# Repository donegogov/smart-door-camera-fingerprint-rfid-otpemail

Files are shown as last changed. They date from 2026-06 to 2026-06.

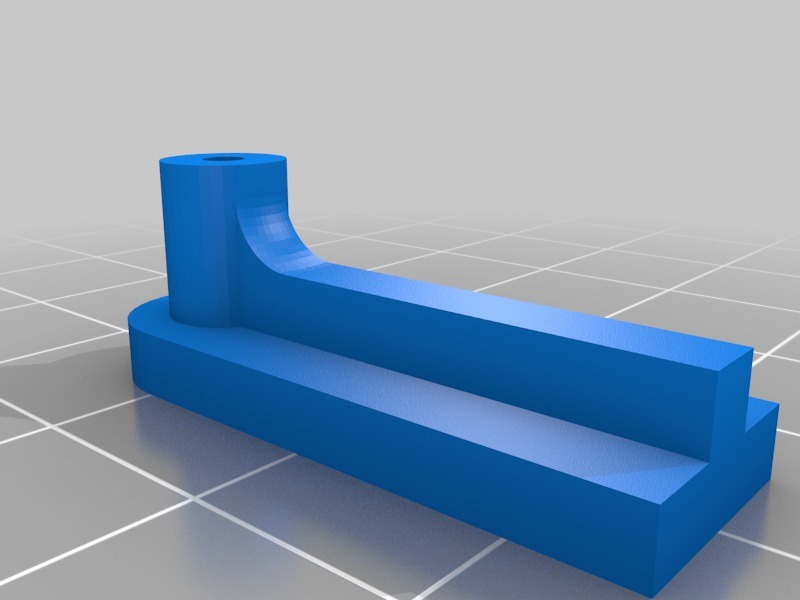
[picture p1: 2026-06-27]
stl for smart door/Super Compact Pan Tilt Camera Mount - 107957/images/bracket.jpg

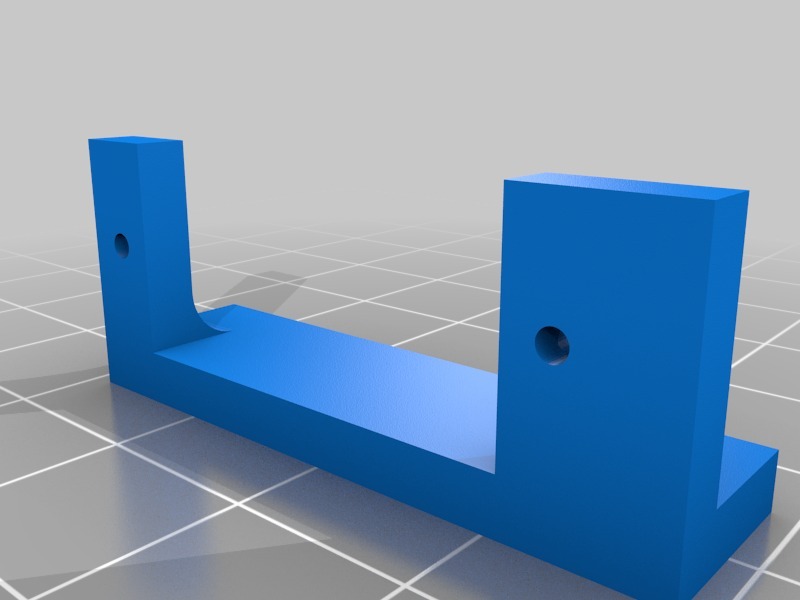
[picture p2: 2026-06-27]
stl for smart door/Super Compact Pan Tilt Camera Mount - 107957/images/vertMount.jpg

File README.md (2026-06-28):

if you like my work donate some crypto

Bitcoin: bc1p0pmdvk0g86z0apl4l9f0rgymtfvcjtlekkm47hyptl5zf8ask6hqpf82un

Ethereum: 0x4F641266B906AcEA1Ed106FDD50978EE5337e3e7

Solana: 4UCTxasy88uFfBvxVqoLxvh8sPomCSJ1Ljoxbf5Xc1ef

# 🔒 Pametna Vrata — Multi-Layer Smart Door Security System

Sistem za pametno zakluchuvanje so **5 sloevi na zashtita**, izgraden na
Raspberry Pi. Raboti kako **dopolnitelen sloj** nad obichnata brava so kluc.

> **Vazhno:** Ova e DIY/hobi proekt i DOPOLNITELEN sloj na zashtita. Obichnata
> brava so kluc OSTANUVA glavnata zashtita. Ne se potпiraj samo na ova za
> vistinska bezbednost na dom.

---

## 📋 Sodrzhina
1. Shto pravi sistemot
2. Arhitektura (zoshto DVA uredi)
3. Shto ti treba (hardver)
4. Povrzuvanje (pinout)
5. Instalacija od NULA
6. Mrezha (Ethernet megju dvata Pi)
7. TLS sertifikati
8. Enroll (lica, otpechatoci, kartichki)
9. Pushtanje
10. Shtelovanje i problemi
11. Bezbednost — kako raboti

---

## 1. Shto pravi sistemot

Koga nekoj ke se priblizhi do vratata:

1. 📷 **Kamera na pan/tilt** detektira dvizhenje i SLEDI go liceto (mazno)
2. 🧠 **Face recognition** — proveruva dali e poznat chlen ili nepoznat
   - Nepoznat → praka ALERT email so slika do sopstvenikot
   - Poznat → prodolzhuva na sledniot sloj
3. 👆 **Otpechatok od prst**
4. 📧 **OTP kod** — ispraten na email, se vnesuva na tastatura
5. 💳 **RFID kartichka**

Ako SITE 5 proverki pominat → vratata se otkluchuva.
LCD ekran prikazhuva status na sekoj chekor.

---

## 2. Arhitektura — zoshto DVA uredi?

Sistemot koristi **dva Raspberry Pi** za maksimalna bezbednost:

```
   NADVOR (RPi4, na vratata)            VNATRE (RPi5, zad vratata)
   +----------------------+            +----------------------+
   | • Kamera + serva      |            | • Face recognition    |
   | • Otpechatok, RFID    |  Ethernet  | • Site proverki       |
   | • Tastatura, LCD      |<==(TLS)==> | • Bazi + tajni        |
   | • SLEDI lokalno       |            | • OTP (email)         |
   | x NEMA tajni          |            | • ODLUCHUVA           |
   | x NEMA bazi           |            | • Komanduva BRAVA     |
   | x NE odluchuva        |            | 🔒 BRAVA (vnatre)     |
   +----------------------+            +----------------------+
```

**Zoshto vaka?** Nadvoreshniot Pi e fizichki dostapen (napagjach moze da go
dofati). Zatoa toj NEMA nishto vredno — bez tajni, bez bazi, bez moc da
otkluchи. Samo CHITA senzori i PRAKA surovi podatoci vnatre. Mozokot
(odluka + brava) e VNATRE, nedostapen.

Duri i da nekoj go ukrade ili hakira nadvoreshniot Pi → dobiva bezvreden
"preprakjach". Ne moze da otkluchi bez da pomine SITE proverki vnatre.

---

## 3. Shto ti treba (hardver)

| Komponenta | Uloga | Kade |
|---|---|---|
| Raspberry Pi 4 (4-8GB) | sledi + senzori | NADVOR |
| Raspberry Pi 5 | mozok + odluka | VNATRE |
| Pi Camera v3 (NoIR za nok) | lice | NADVOR |
| SunFounder Fusion HAT+ | serva + napojuvanje | NADVOR |
| 2x servo (pan/tilt) | dvizhenje na kamera | NADVOR |
| Fingerprint senzor (UART) | otpechatok | NADVOR |
| RC522 RFID chitac | kartichki | NADVOR |
| 4x4 tastatura | OTP vnes | NADVOR |
| 16x2 LCD (I2C) | status | NADVOR |
| Rele + brava (FAIL-SECURE) | zakluchuvanje | VNATRE |
| Ethernet kabel + armored door loop | vrska | megju dvata |

**Napojuvanje:** NADVOR preku Fusion HAT+ (eden 5V/3A USB-C za Pi+serva).
VNATRE obichen RPi5 napojuvac (5V/5A).

> **NoIR kamera** = gleda vo temnina so IR svetlo. Dobro za vrata. Preku den
> boite izgledaat malku rozevo.

---

## 4. Povrzuvanje (pinout)

Site pinovi se **BCM** broevi.

### NADVOR (RPi4)
| Komponenta | Povrzuvanje |
|---|---|
| **Serva pan/tilt** | Fusion HAT kanali **P0** (pan), **P1** (tilt) |
| **Fingerprint** UART | TX→GPIO15, RX→GPIO14, 3.3V, GND (`/dev/serial0`) |
| **RC522** SPI | SDA→GPIO8, SCK→GPIO11, MOSI→GPIO10, MISO→GPIO9, RST→GPIO25, **3.3V**, GND |
| **Tastatura 4x4** | redovi 19,13,6,5 / koloni 21,20,22,27 |
| **LCD I2C** | SDA→GPIO2, SCL→GPIO3 (**hardverska i2c-1**), 5V, GND |
| **Vrska kon VNATRE** | Ethernet (eth0) |

> ⚠️ RC522 SAMO na **3.3V** (na 5V gori!). Fingerprint TX↔RX se VKRSTENI.

### VNATRE (RPi5)
| Komponenta | Pin |
|---|---|
| Rele za brava | GPIO17 (FAIL-SECURE: bez struja = zakluceno) |
| Ethernet | eth0 → kon NADVOR |
| Monitor | HDMI |

---

## 5. Instalacija od NULA

### 5.1 — Snimi OS na dvete SD kartichki
Koristi **Raspberry Pi Imager**. Za OBATA:
- OS: **Raspberry Pi OS (64-bit) — Bookworm**
- Vo postavki (⚙️): vkluchi SSH, postavi korisnik/lozinka, WiFi

### 5.2 — Prv boot i azhuriranje (OBATA)
```bash
sudo apt update && sudo apt full-upgrade -y
```

### 5.3 — Svali go proektot
Stavi ja `nadvor/` papka na RPi4, `vnatre/` papka na RPi5.

### 5.4 — Pushti install skripta

**NADVOR (RPi4):**
```bash
cd nadvor
chmod +x install_nadvor.sh
./install_nadvor.sh
sudo reboot
```
**VNATRE (RPi5):**
```bash
cd vnatre
chmod +x install_vnatre.sh
./install_vnatre.sh
sudo reboot
```

> ⏳ Na VNATRE, dlib KOMPAJLIRA 10-30 min. Normalno. NADVOR e pobrz (nema dlib).

### 5.5 — Sekogash aktiviraj venv pred rabota
```bash
cd nadvor   # ili vnatre
source venv/bin/activate
```

---

## 6. Mrezha — Ethernet megju dvata Pi

Preporachano: **direkten kabel Pi-na-Pi** so staticki IP.

> Bookworm koristi **NetworkManager** (ne dhcpcd!). Koristi `nmcli`.

Najdi go imeto na ethernet vrskata:
```bash
nmcli con show          # baraj "ethernet" tip (npr "eth0" ili "Wired connection 1")
```

**VNATRE (RPi5)** — IP 10.0.0.1:
```bash
sudo nmcli con mod "<ime>" ipv4.method manual ipv4.addresses 10.0.0.1/24
sudo nmcli con mod "<ime>" ipv4.never-default yes
sudo nmcli con up "<ime>"
```
**NADVOR (RPi4)** — IP 10.0.0.2:
```bash
sudo nmcli con mod "<ime>" ipv4.method manual ipv4.addresses 10.0.0.2/24
sudo nmcli con mod "<ime>" ipv4.never-default yes
sudo nmcli con up "<ime>"
```

Povrzhi go kabelot (obata Pi vkluceni!), pa testiraj od NADVOR:
```bash
ping 10.0.0.1     # treba da odgovara
```
Vo `nadvor/config_vrska.py` proveri: `VNATRE_IP = "10.0.0.1"`

> Ethernet kabelot pominuva niz **armored door cable** (povrshinski, bez dupcenje dzid).

---

## 7. TLS sertifikati (sifrirana vrska)

Pushti **EDNASH**:
```bash
chmod +x generiraj_sertifikati.sh
./generiraj_sertifikati.sh
```
Kopiraj:
- **VNATRE** (vnatre/): `ca.crt`, `vnatre.crt`, `vnatre.key`
- **NADVOR** (nadvor/): `ca.crt`, `nadvor.crt`, `nadvor.key`

> 🔑 `ca.key` chuvaj go OFFLINE. Privatnite `.key` NIKOGASH ne gi sodeluvaj.

---

## 8. Enroll — lica, otpechatoci, kartichki

Senzorite se NADVOR, bazите VNATRE → dva chekori.

### 8.1 LICA
NADVOR:
```bash
cd nadvor && source venv/bin/activate
python3 headshots.py        # ime, SPACE=slikaj, Q=kraj (10-15 sliki/chlen)
```
Kopiraj `dataset/` na VNATRE, pa:
```bash
cd vnatre && source venv/bin/activate
python3 train_model.py      # pravi encodings.pickle
```

### 8.2 OTPECHATOCI
NADVOR:
```bash
python3 enroll_otpechatok.py    # registriraj prst, zapamti finger_id
```
VNATRE — vo `otpechatoci.json`:
```json
{"1": "Done", "2": "Valentina", "3": "Vasil"}
```

### 8.3 RFID KARTICHKI
NADVOR:
```bash
python3 rfid_zapis.py       # zapisuva token, ti dava UID + Token
```
VNATRE:
```bash
python3 rfid_dodaj.py       # vnesi UID+Token, presmetuva hash, zachuvuva
```

### 8.4 Email (Mailgun) — na VNATRE
Vo `vnatre/.env` popolni `MAILGUN_API_KEY`, `MAILGUN_DOMAIN`, `ADMIN_EMAIL`.
Vo `vnatre/config_vnatre.py` smeni `EMAILS` so iminjata na familijata.

---

## 9. Pushtanje

**Prvo VNATRE (RPi5):**
```bash
cd vnatre && source venv/bin/activate && python3 server.py
```
**Potoa NADVOR (RPi4):**
```bash
cd nadvor && source venv/bin/activate && python3 main_nadvor.py
```

### Avtomatski na boot (systemd) — primer za VNATRE
```bash
sudo nano /etc/systemd/system/vrata.service
```
```ini
[Unit]
Description=Pametna Vrata
After=network.target

[Service]
User=donatello
WorkingDirectory=/home/donatello/vnatre
ExecStart=/home/donatello/vnatre/venv/bin/python /home/donatello/vnatre/server.py
Restart=on-failure

[Install]
WantedBy=multi-user.target
```
```bash
sudo systemctl enable vrata.service && sudo systemctl start vrata.service
```

---

## 10. Shtelovanje i chesti problemi

### Serva
| Problem | Reshenie |
|---|---|
| servo odi naopaku | `PAN_DIR`/`TILT_DIR` = -1 vo config.py |
| servo ne mrda | proveri kanal (P0/P1), kabli, Fusion HAT napojuvanje |

### Sledenje
| Problem | Reshenie |
|---|---|
| haoticno dvizhenje | namali `SCAN_STEP`, zgolemi `SCAN_DELAY` |
| ne gleda dvizhenje | namali `MIN_AREA` |
| premnogu osetlivo | zgolemi `MIN_AREA` i `THRESHOLD_SENSITIVITY` |

### Kamera
| Problem | Reshenie |
|---|---|
| ne bootira so HAT | proveri kabel na kamera (chest problem!) |
| mnogu zoom | `kamera.py` koristi ScalerCrop na cel senzor (full FoV) |
| lista prazna | kabel labav ili lош |

### Mrezha
| Problem | Reshenie |
|---|---|
| ping ne pominuva | proveri kabel, obata Pi vkluceni, IP adresi |
| `nmcli con up` greshka | kabelot mora da e povrzan PRVO |
| TLS greshka | sertifikatите kopirani vo dvete papki? |

### Fingerprint
| Problem | Reshenie |
|---|---|
| UART Input/output error | serial konzola iskluchena? TX↔RX vkrsteni? |

---

## 11. Bezbednost — kako raboti

| Sloj | Zashtita |
|---|---|
| **Mozok vnatre** | NADVOR nema tajni/bazi/odluka → ukraden = bezvreden |
| **TLS sifriranje** | nikoj na mrezhata ne moze da slusha/imitira |
| **OTP** | razlichen sekoj pat, na email → anti-replay |
| **RFID hash** | samo SHA-256 hash vnatre, salt ne patuva, kartichka bez lichni podatoci |
| **SSH kluc-samo** | bez lozinka, samo so privaten kluc |
| **FAIL-SECURE brava** | bez struja = zakluceno |
| **Obichen kluc** | GLAVNA zashtita — ova e DOPOLNITELEN sloj |

### SSH hardening
```bash
ssh-keygen -t ed25519              # na tvojot kompjuter
ssh-copy-id korisnik@<ip-na-Pi>
# vo /etc/ssh/sshd_config: PasswordAuthentication no
sudo systemctl restart ssh
```

---

## 📁 Struktura na fajlovi

### nadvor/ (RPi4)
```
main_nadvor.py       glavna (sledi + vodi niz faktori)
config.py            postavki (pinovi, kamera, serva)
config_vrska.py      IP na VNATRESHNIOT Pi
kamera.py            video stream
sledenje.py          Fusion HAT serva + motion
tastatura.py         4x4 tastatura
otpechatok.py        fingerprint
rfid_chitac.py       RFID (samo chita)
lcd.py               LCD status
vrska.py             TLS komunikacija
headshots.py         ALATKA: slikanje lica
enroll_otpechatok.py ALATKA: otpechatoci
rfid_zapis.py        ALATKA: RFID token
install_nadvor.sh    instalacija
generiraj_sertifikati.sh  TLS
```

### vnatre/ (RPi5)
```
server.py            glavna (TCP server + odluka + brava)
config_vnatre.py     postavki
prepoznavanje.py     face recognition
proverki.py          proverki (+ tajni/bazi)
email_notifikacija.py  Mailgun
brava.py             rele
vrska.py             TLS komunikacija
train_model.py       ALATKA: encodings.pickle
rfid_dodaj.py        ALATKA: RFID hash vo baza
install_vnatre.sh    instalacija
generiraj_sertifikati.sh  TLS
.env                 TAJNI - NE se sodeluva!
```

### Fajlovi shto TI gi pravish (ne se vo repo)
```
vnatre/encodings.pickle    lica
vnatre/korisnici.json      RFID hashevi
vnatre/otpechatoci.json    finger_id → ime
vnatre/.env                tajni
ca.crt, *.crt, *.key       TLS sertifikati
```

---

## ⚖️ Odgovornost

Edukativen/hobi proekt. Avtorot ne e odgovoren za bezbednost na tvoj dom.
Sekogash chuvaj ja obichnata brava so kluc kako GLAVNA zashtita.

Pridonesi i podobruvanja se dobredojdeni! 🚀

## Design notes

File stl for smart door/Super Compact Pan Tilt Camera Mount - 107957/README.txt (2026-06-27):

Super Compact Pan Tilt Camera Mount by AtomKemp on Thingiverse: https://www.thingiverse.com/thing:107957

Summary:
This was intended for use on a quad-rotor project, although it can be mounted on really anything. I used two Hitec HS-55 sub-micro servos and it whips the camera around without any problem. Enjoy!If you like this project, or would like to know more about 3D printing, check out my new book "The Makerspace Workbench" from Maker Media!

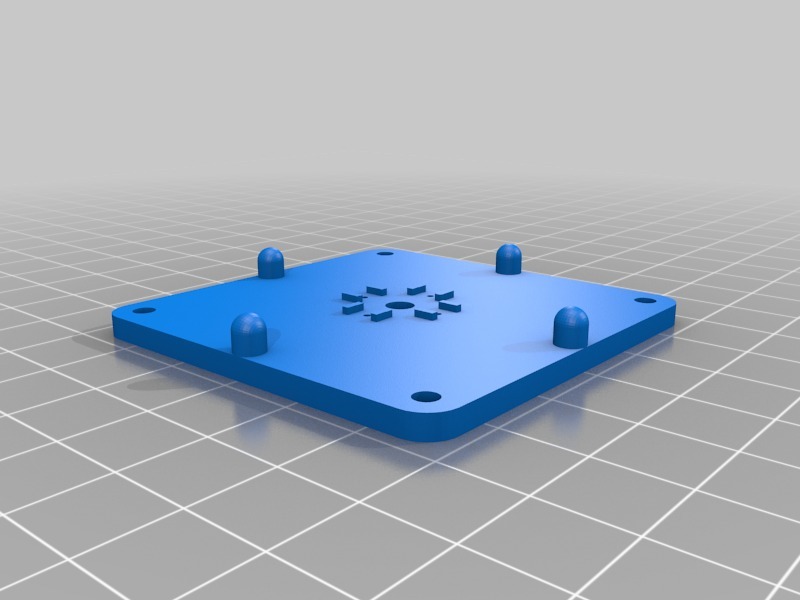
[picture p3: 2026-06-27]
stl for smart door/Super Compact Pan Tilt Camera Mount - 107957/images/panTiltBase.jpg

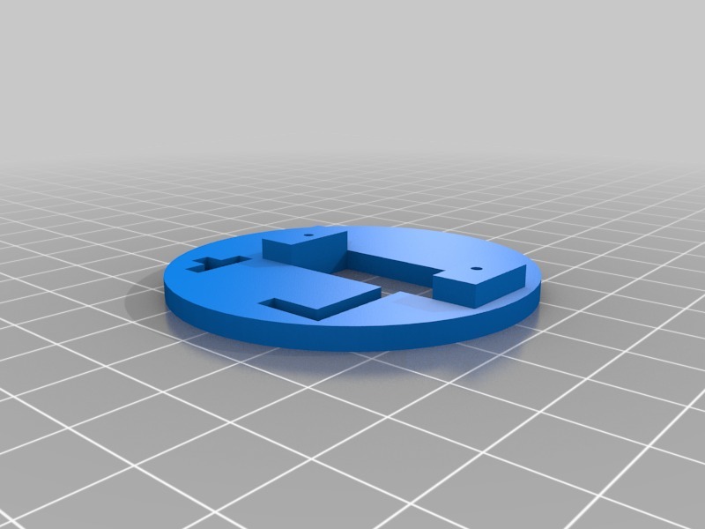
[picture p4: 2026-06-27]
stl for smart door/Super Compact Pan Tilt Camera Mount - 107957/images/panTilt.jpg

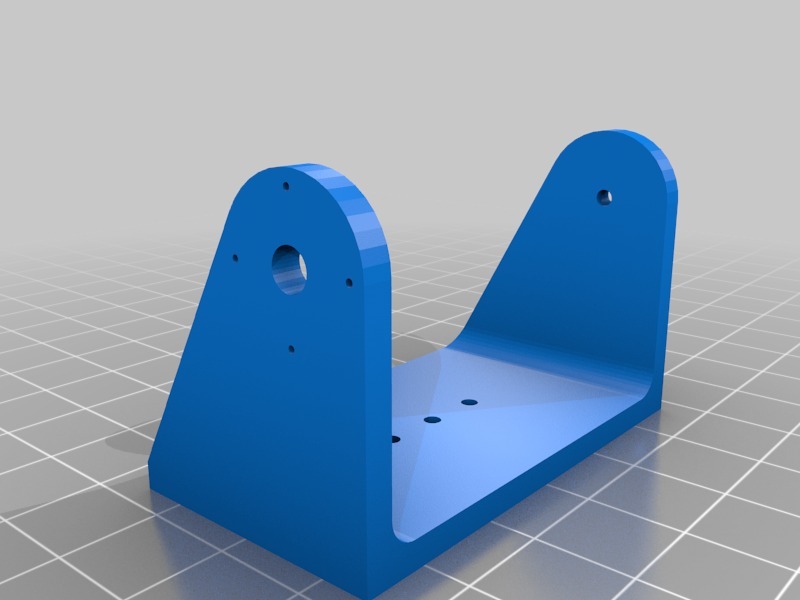
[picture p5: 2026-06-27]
stl for smart door/Super Compact Pan Tilt Camera Mount - 107957/images/cameraMount.jpg

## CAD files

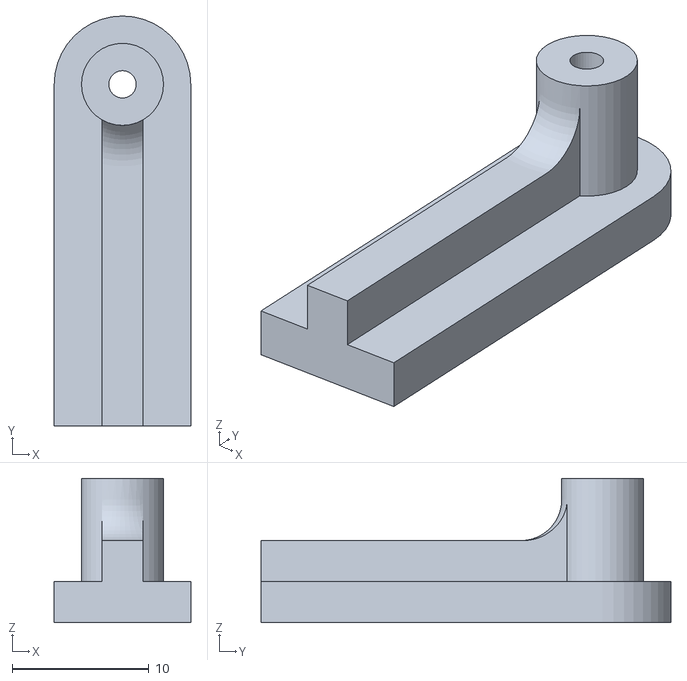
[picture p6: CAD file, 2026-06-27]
stl for smart door/Super Compact Pan Tilt Camera Mount - 107957/files/bracket.STL
10.0 x 30.0 x 10.6

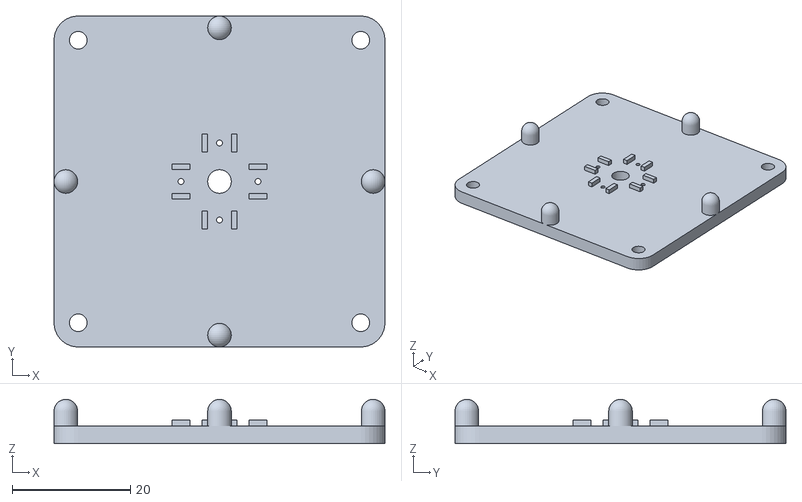
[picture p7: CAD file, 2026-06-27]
stl for smart door/Super Compact Pan Tilt Camera Mount - 107957/files/panTiltBase.STL
56.0 x 56.0 x 7.50

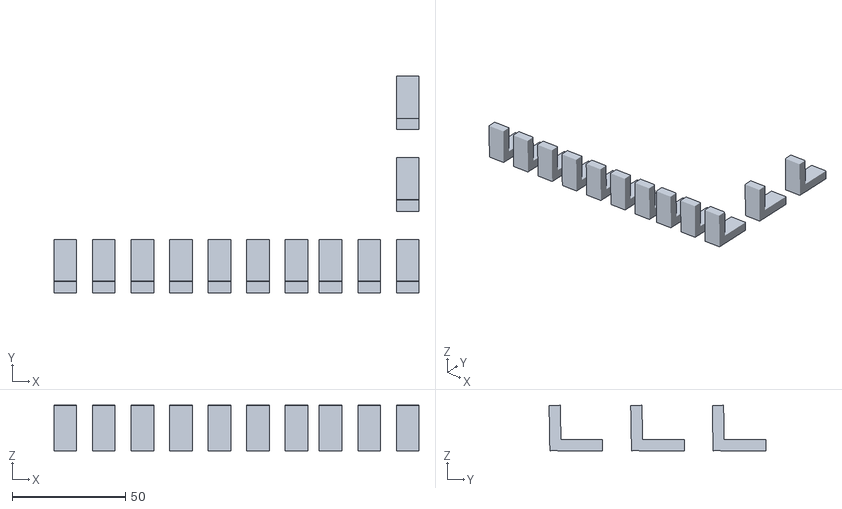
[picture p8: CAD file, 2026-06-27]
stl for smart door/drzaci.stl
161.0 x 95.7 x 20.1

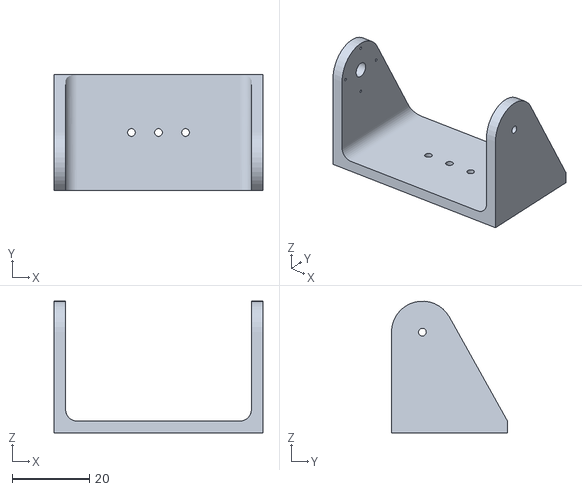
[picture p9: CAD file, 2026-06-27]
stl for smart door/Super Compact Pan Tilt Camera Mount - 107957/files/cameraMount.STL
54.0 x 30.0 x 34.0

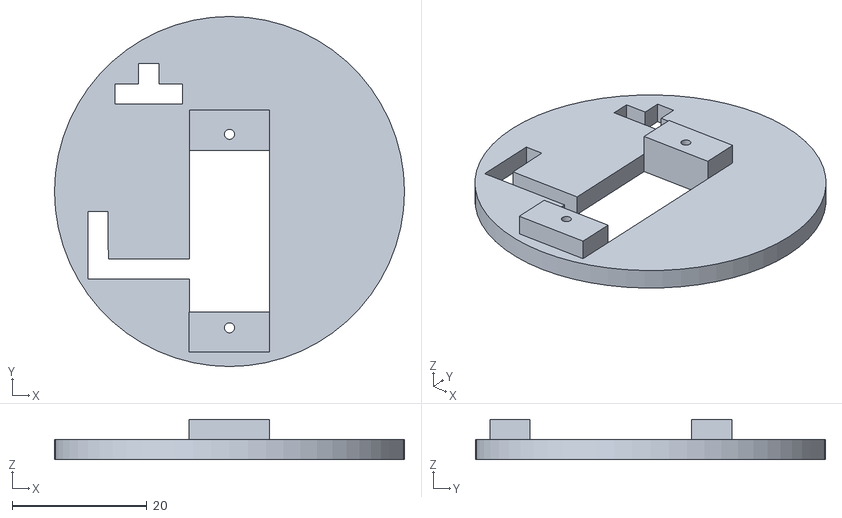
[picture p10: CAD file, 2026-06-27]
stl for smart door/Super Compact Pan Tilt Camera Mount - 107957/files/panTilt.STL
52.0 x 52.0 x 6.00

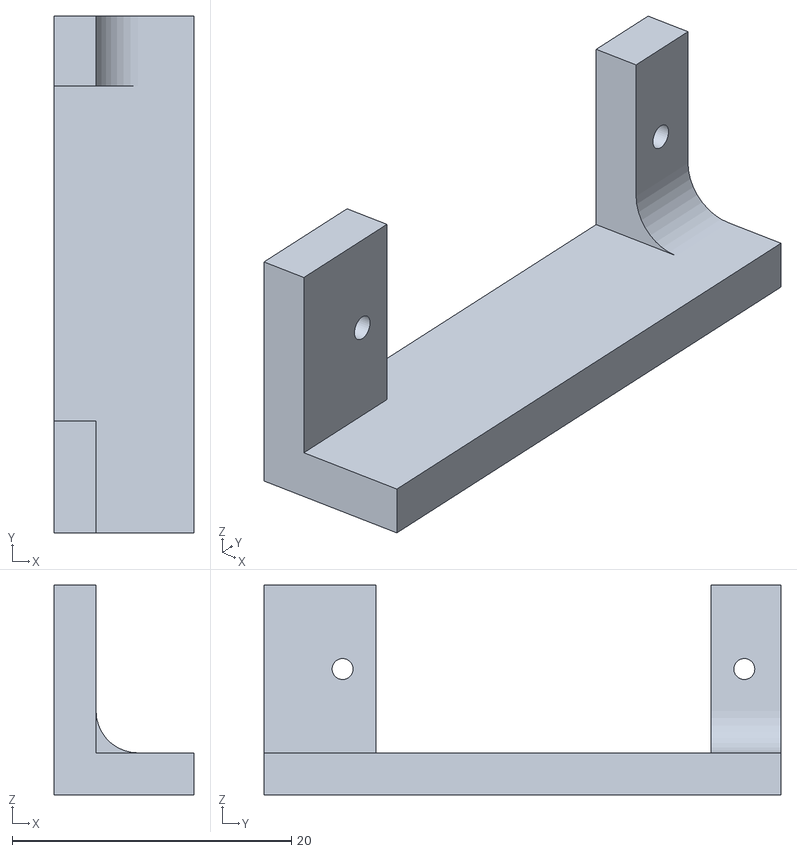
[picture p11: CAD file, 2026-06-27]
stl for smart door/Super Compact Pan Tilt Camera Mount - 107957/files/vertMount.STL
10.00 x 37.0 x 15.0

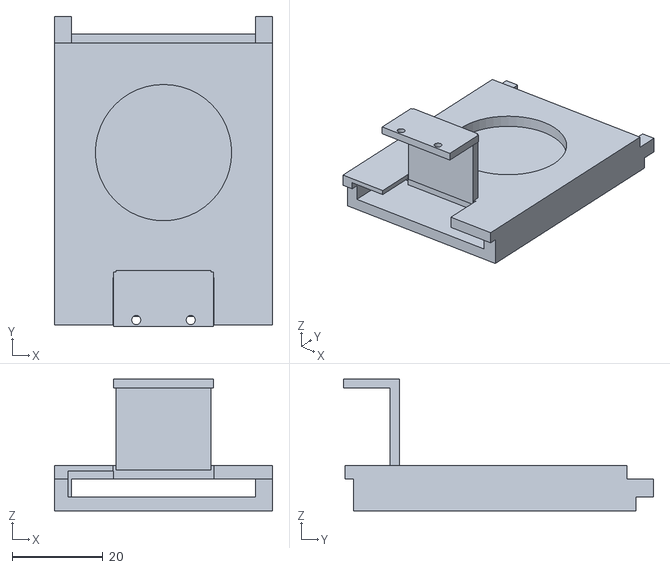
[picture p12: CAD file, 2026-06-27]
stl for smart door/rfid_housing_v1.3.stl
48.0 x 68.3 x 29.0

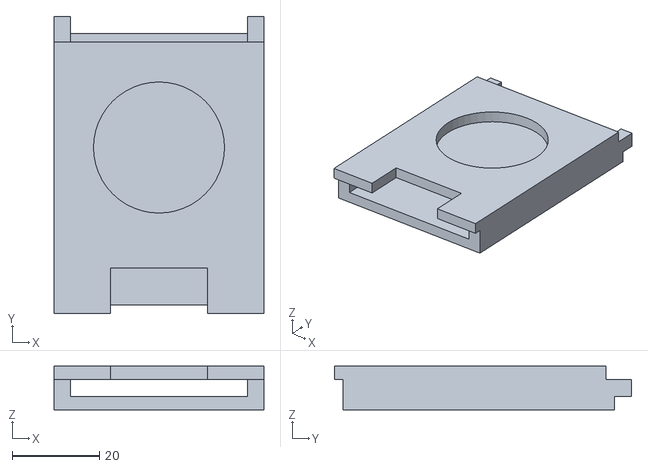
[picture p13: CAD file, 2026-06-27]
stl for smart door/rfid_housing.stl
48.0 x 68.0 x 10.0

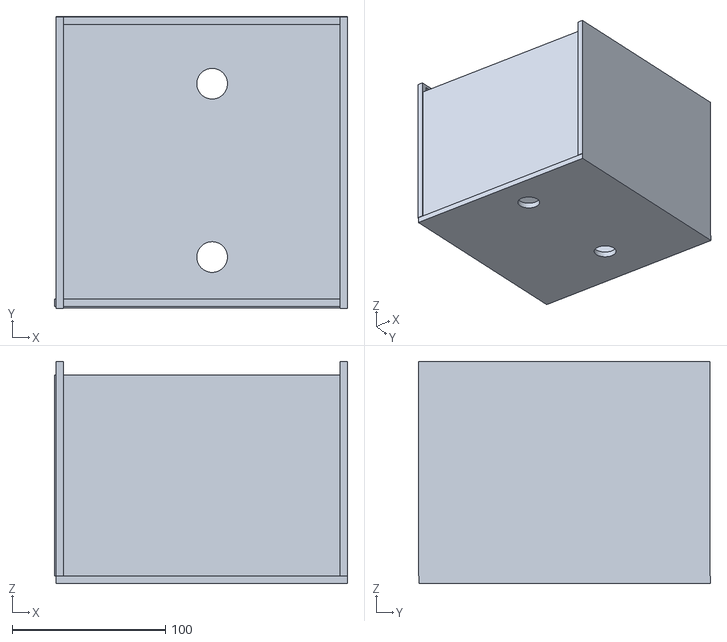
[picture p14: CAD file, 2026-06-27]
stl for smart door/razvodna_kutija_v2.0.stl
191.0 x 190.4 x 145.0

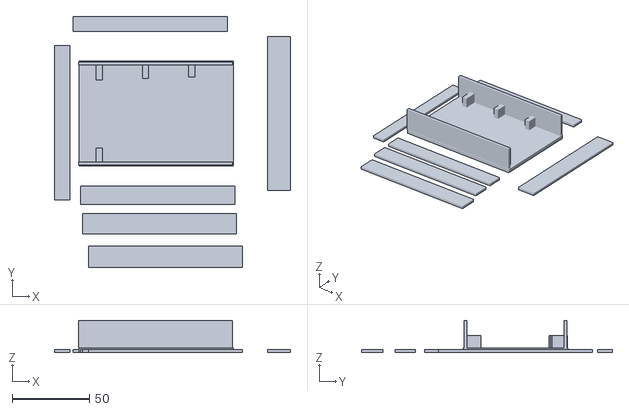
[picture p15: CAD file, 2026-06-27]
stl for smart door/lcd_housing_v2.stl
153.0 x 163.0 x 21.0

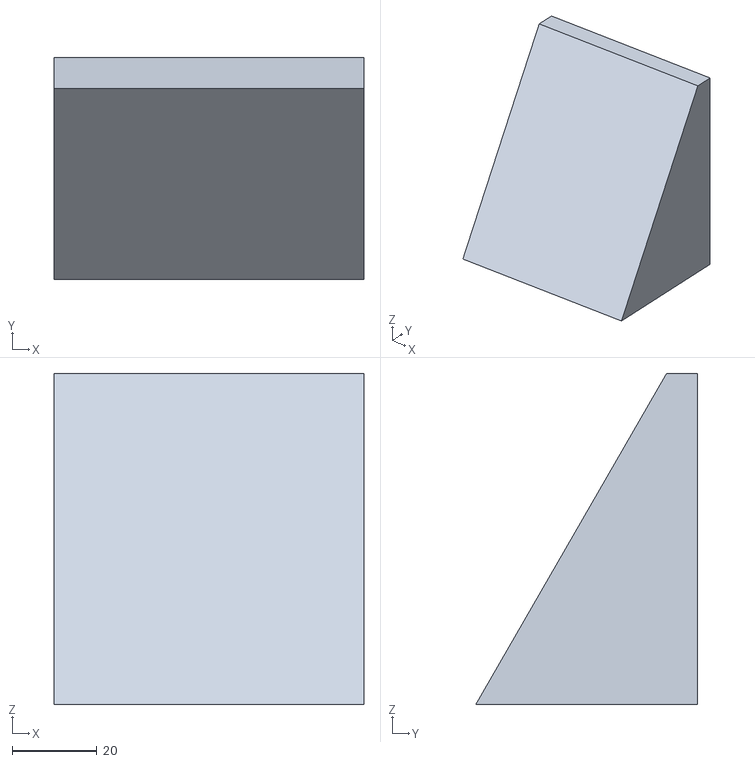
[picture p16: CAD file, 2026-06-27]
stl for smart door/tastatura_housing_v1.0.stl
73.0 x 52.2 x 78.0

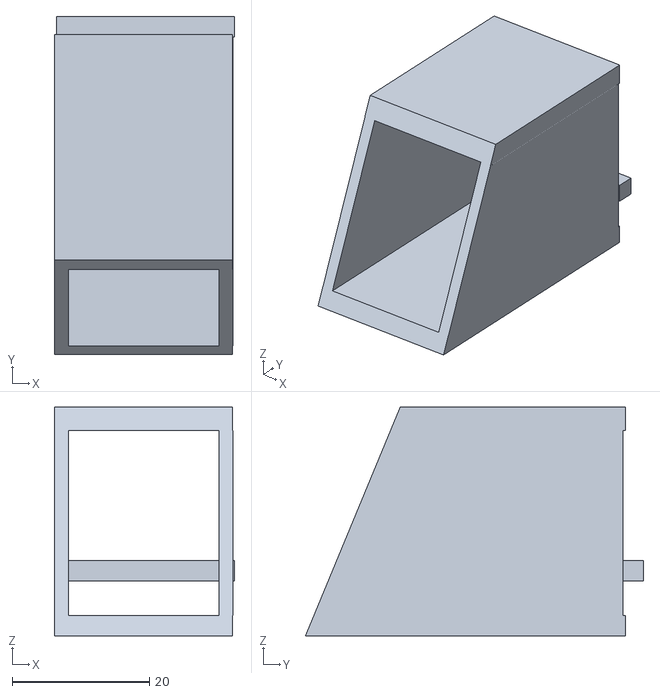
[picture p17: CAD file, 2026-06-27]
stl for smart door/fingerprint_housing_v2.0.stl
26.3 x 49.3 x 33.4

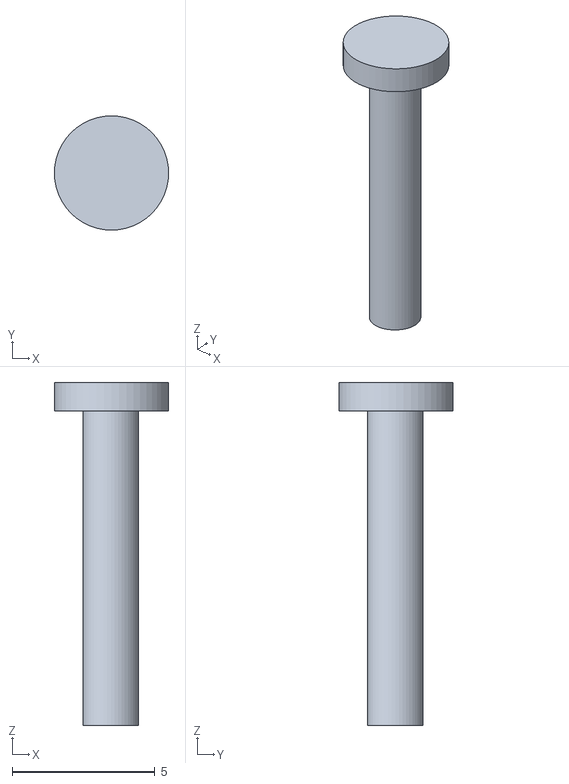
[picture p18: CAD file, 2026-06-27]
stl for smart door/rfid_screw.stl
4.00 x 4.00 x 12.0

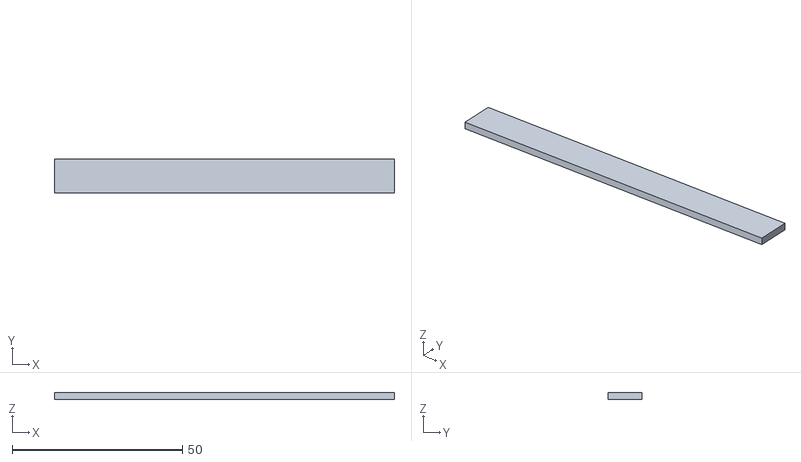
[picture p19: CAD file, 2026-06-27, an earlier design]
stl for smart door/lcd_housing_v1.1.stl
100.0 x 10.0 x 2.00

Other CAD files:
stl for smart door/fingerprint_housing_v1.1.stl
stl for smart door/fingerprint_housing_v1.0.stl
stl for smart door/lcd_housing_v1.2.stl
stl for smart door/razvodna_kutija_v1.0.stl
stl for smart door/lcd_housing_v1.0.stl
stl for smart door/lcd_housing_v1.3.stl
stl for smart door/rfid_housing_v1.1.stl
stl for smart door/rfid_housing_v1.2.stl

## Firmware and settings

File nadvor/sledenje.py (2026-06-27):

# -*- coding: utf-8 -*-
# sledenje.py
#
# SunFounder Fusion HAT:
#   PAN  = P0
#   TILT = P1
#
# Реални Fusion HAT агли:
#   PAN:  -30° до +30°
#   TILT: -90° горе до -60° долу
#
# Во функцијата postavi(x, y) продолжуваме да користиме логички 0-180:
#   PAN 60  -> Fusion -30°
#   PAN 90  -> Fusion   0°
#   PAN 120 -> Fusion +30°
#
#   TILT 0  -> Fusion -90° горе
#   TILT 15 -> Fusion -75° средина
#   TILT 30 -> Fusion -60° долу

import time
import math
from enum import Enum

import cv2
from fusion_hat.servo import Servo

import config as cfg

import numpy as np


# ============================================================
#                    ВИД НА ДВИЖЕЊЕ
# ============================================================

class MovementPattern(Enum):
    RECTANGLE = "rectangle"
    ELLIPSE = "ellipse"
    CIRCLE = "circle"
    INFINITY = "infinity"


# ОВДЕ ЈА ИЗБИРАШ ФОРМАТА:
MOVEMENT_PATTERN = MovementPattern.ELLIPSE

# Примери:
# MOVEMENT_PATTERN = MovementPattern.RECTANGLE
# MOVEMENT_PATTERN = MovementPattern.ELLIPSE
# MOVEMENT_PATTERN = MovementPattern.CIRCLE
# MOVEMENT_PATTERN = MovementPattern.INFINITY


# Колку секунди трае еден цел круг/елипса/осмица.
# Поголема вредност = побавно.
MOVEMENT_CYCLE_SECONDS = getattr(
    cfg,
    "MOVEMENT_CYCLE_SECONDS",
    10.0
)


# ============================================================
#                         CONFIG
# ============================================================
# Најмалку 5% од сликата мора да биде еден голем moving object.
MOTION_MIN_BLOB_RATIO = getattr(
    cfg,
    "MOTION_MIN_BLOB_RATIO",
    0.05
)

# Ако повеќе од 35% од целата слика се сменило,
# најверојатно се движела камерата.
MOTION_MAX_SCENE_CHANGE = getattr(
    cfg,
    "MOTION_MAX_SCENE_CHANGE",
    0.35
)

# Минимална ширина/висина на moving object.
MOTION_MIN_WIDTH_RATIO = getattr(
    cfg,
    "MOTION_MIN_WIDTH_RATIO",
    0.10
)

MOTION_MIN_HEIGHT_RATIO = getattr(
    cfg,
    "MOTION_MIN_HEIGHT_RATIO",
    0.20
)

# Колку последователни frames мора да има големо движење.
MOTION_CONFIRM_FRAMES = getattr(
    cfg,
    "MOTION_CONFIRM_FRAMES",
    2
)

# Каде да цели во moving object.
# 0.0 е самиот врв, 0.5 е средина.
MOTION_HEAD_FACTOR = getattr(
    cfg,
    "MOTION_HEAD_FACTOR",
    0.18
)

# Максимално дозволено поместување на целата камера.
MOTION_MAX_CAMERA_SHIFT_RATIO = getattr(
    cfg,
    "MOTION_MAX_CAMERA_SHIFT_RATIO",
    0.15
)

_motion_confirm_count = 0
_motion_last_center = None

PCA_PAN_CHANNEL = getattr(
    cfg,
    "PCA_PAN_CHANNEL",
    "P0"
)

PCA_TILT_CHANNEL = getattr(
    cfg,
    "PCA_TILT_CHANNEL",
    "P1"
)

PAN_DIR = getattr(cfg, "PAN_DIR", 1)
TILT_DIR = getattr(cfg, "TILT_DIR", 1)


# Логички агли 0-180.
# Овие вредности ги даваат твоите физички Fusion агли.
PAN_MIN = getattr(cfg, "PAN_MIN", 60)
PAN_MAX = getattr(cfg, "PAN_MAX", 120)

TILT_MIN = getattr(cfg, "TILT_MIN", 0)
TILT_MAX = getattr(cfg, "TILT_MAX", 30)


PAN_CENTER = getattr(
    cfg,
    "PAN_CENTER",
    (PAN_MIN + PAN_MAX) / 2.0
)

TILT_CENTER = getattr(
    cfg,
    "TILT_CENTER",
    (TILT_MIN + TILT_MAX) / 2.0
)


SNAKE_PAN_MIN = getattr(
    cfg,
    "SNAKE_PAN_MIN",
    PAN_MIN
)

SNAKE_PAN_MAX = getattr(
    cfg,
    "SNAKE_PAN_MAX",
    PAN_MAX
)

SNAKE_TILT_UP = getattr(
    cfg,
    "SNAKE_TILT_UP",
    TILT_MIN
)

SNAKE_TILT_DOWN = getattr(
    cfg,
    "SNAKE_TILT_DOWN",
    TILT_MAX
)

SNAKE_CENTER_TILT = getattr(
    cfg,
    "SNAKE_CENTER_TILT",
    TILT_CENTER
)


# Брзина само за RECTANGLE режим.
# Степени во секунда.
SNAKE_SPEED = getattr(
    cfg,
    "SNAKE_SPEED",
    25.0
)

SNAKE_EPS = getattr(
    cfg,
    "SNAKE_EPS",
    0.7
)


# Motion detection config
MIN_AREA = getattr(cfg, "MIN_AREA", 800)

THRESHOLD_SENSITIVITY = getattr(
    cfg,
    "THRESHOLD_SENSITIVITY",
    25
)

BLUR_SIZE = getattr(
    cfg,
    "BLUR_SIZE",
    7
)

HEAD_FACTOR = getattr(
    cfg,
    "HEAD_FACTOR",
    0.35
)

verbose = getattr(
    cfg,
    "verbose",
    getattr(cfg, "VERBOSE", False)
)


# ============================================================
#                        SERVO INIT
# ============================================================

pan_servo = Servo(PCA_PAN_CHANNEL)
tilt_servo = Servo(PCA_TILT_CHANNEL)


# ============================================================
#                    ВНАТРЕШНИ ВРЕДНОСТИ
# ============================================================

_pan_radius = abs(
    SNAKE_PAN_MAX - SNAKE_PAN_MIN
) / 2.0

_tilt_radius = abs(
    SNAKE_TILT_DOWN - SNAKE_TILT_UP
) / 2.0

_pan_path_center = (
    SNAKE_PAN_MIN + SNAKE_PAN_MAX
) / 2.0

_tilt_path_center = (
    SNAKE_TILT_UP + SNAKE_TILT_DOWN
) / 2.0


# Rectangle/snake патеката останува како претходно:
# средина лево -> средина десно -> горе десно
# -> горе лево -> долу лево -> долу десно итн.
_RECTANGLE_POINTS = [
    (SNAKE_PAN_MIN, SNAKE_CENTER_TILT),
    (SNAKE_PAN_MAX, SNAKE_CENTER_TILT),

    (SNAKE_PAN_MAX, SNAKE_TILT_UP),
    (SNAKE_PAN_MIN, SNAKE_TILT_UP),

    (SNAKE_PAN_MIN, SNAKE_TILT_DOWN),
    (SNAKE_PAN_MAX, SNAKE_TILT_DOWN),

    (SNAKE_PAN_MAX, SNAKE_TILT_UP),
    (SNAKE_PAN_MIN, SNAKE_TILT_UP),

    (SNAKE_PAN_MIN, SNAKE_TILT_DOWN),
    (SNAKE_PAN_MAX, SNAKE_TILT_DOWN),
]


# Почетна позиција зависно од избраната форма.
if MOVEMENT_PATTERN == MovementPattern.RECTANGLE:
    _cur_x = float(SNAKE_PAN_MIN)
    _cur_y = float(SNAKE_CENTER_TILT)

elif MOVEMENT_PATTERN == MovementPattern.ELLIPSE:
    _cur_x = float(SNAKE_PAN_MAX)
    _cur_y = float(_tilt_path_center)

elif MOVEMENT_PATTERN == MovementPattern.CIRCLE:
    _circle_radius = min(_pan_radius, _tilt_radius)

    _cur_x = float(
        _pan_path_center + _circle_radius
    )
    _cur_y = float(_tilt_path_center)

else:
    # INFINITY почнува од средина.
    _cur_x = float(_pan_path_center)
    _cur_y = float(_tilt_path_center)


_rectangle_index = 1
_path_phase = 0.0
_last_tick_time = time.monotonic()

_last_pan_write = None
_last_tilt_write = None


# ============================================================
#                         HELPERS
# ============================================================

def _clamp(value, minimum, maximum):
    return max(minimum, min(maximum, value))


def _vo_fusion_agol(angle_0_180):
    """
    Претвора логички 0-180 во Fusion HAT -90..90.

    0   -> -90
    90  -> 0
    180 -> +90
    """
    return float(angle_0_180) - 90.0


def _write_servos(x, y):
    """
    Праќа агли до Fusion HAT.

    x и y се во логичкиот 0-180 систем.
    """

    global _last_pan_write
    global _last_tilt_write

    x = _clamp(
        float(x),
        PAN_MIN,
        PAN_MAX
    )

    y = _clamp(
        float(y),
        TILT_MIN,
        TILT_MAX
    )

    pan_angle = (
        _vo_fusion_agol(x) * PAN_DIR
    )

    tilt_angle = (
        _vo_fusion_agol(y) * TILT_DIR
    )

    pan_angle = int(
        round(
            _clamp(
                pan_angle,
                -90,
                90
            )
        )
    )

    tilt_angle = int(
        round(
            _clamp(
                tilt_angle,
                -90,
                90
            )
        )
    )

    # Не праќај иста вредност постојано.
    # Така има помалку зуење од сервата.
    if pan_angle != _last_pan_write:
        pan_servo.angle(pan_angle)
        _last_pan_write = pan_angle

    if tilt_angle != _last_tilt_write:
        tilt_servo.angle(tilt_angle)
        _last_tilt_write = tilt_angle

    if verbose:
        print(
            "PAN logical=%.2f fusion=%d | "
            "TILT logical=%.2f fusion=%d"
            % (
                x,
                pan_angle,
                y,
                tilt_angle
            )
        )

    return (
        int(round(x)),
        int(round(y))
    )


def _movement_position(pattern, phase):
    """
    Враќа x/y позиција за:
      ELLIPSE
      CIRCLE
      INFINITY

    phase оди од 0.0 до 1.0.
    """

    angle = (
        phase *
        2.0 *
        math.pi
    )

    if pattern == MovementPattern.ELLIPSE:
        x = (
            _pan_path_center +
            _pan_radius *
            math.cos(angle)
        )

        y = (
            _tilt_path_center +
            _tilt_radius *
            math.sin(angle)
        )

    elif pattern == MovementPattern.CIRCLE:
        radius = min(
            _pan_radius,
            _tilt_radius
        )

        x = (
            _pan_path_center +
            radius *
            math.cos(angle)
        )

        y = (
            _tilt_path_center +
            radius *
            math.sin(angle)
        )

    elif pattern == MovementPattern.INFINITY:
        # Хоризонтална осмица / infinity знак.
        x = (
            _pan_path_center +
            _pan_radius *
            math.sin(angle)
        )

        y = (
            _tilt_path_center +
            _tilt_radius *
            math.sin(2.0 * angle)
        )

    else:
        x = PAN_CENTER
        y = TILT_CENTER

    x = _clamp(
        x,
        PAN_MIN,
        PAN_MAX
    )

    y = _clamp(
        y,
        TILT_MIN,
        TILT_MAX
    )

    return x, y


# ============================================================
#                     ЈАВНИ ФУНКЦИИ
# ============================================================

def postavi(x, y):
    """
    Директно поставување на pan и tilt.

    x и y се во логички 0-180 систем.

    Примери:
        postavi(90, 15)  # центар
        postavi(60, 15)  # pan Fusion -30
        postavi(120, 15) # pan Fusion +30
        postavi(90, 0)   # tilt Fusion -90
        postavi(90, 30)  # tilt Fusion -60
    """

    global _cur_x
    global _cur_y
    global _last_tick_time

    _cur_x = _clamp(
        float(x),
        PAN_MIN,
        PAN_MAX
    )

    _cur_y = _clamp(
        float(y),
        TILT_MIN,
        TILT_MAX
    )

    _last_tick_time = time.monotonic()

    return _write_servos(
        _cur_x,
        _cur_y
    )


def zatvori_serva():
    """
    Ги враќа сервата во твојата реална средина:

      PAN  logical 90 -> Fusion 0°
      TILT logical 15 -> Fusion -75°
    """

    try:
        postavi(
            PAN_CENTER,
            TILT_CENTER
        )

    except Exception as error:
        if verbose:
            print(
                "zatvori_serva error:",
                error
            )


def snake_reset(start_x=None, start_y=None):
    """
    Го ресетира движењето според избраната форма.
    """

    global _cur_x
    global _cur_y

    global _rectangle_index
    global _path_phase
    global _last_tick_time

    _rectangle_index = 1
    _path_phase = 0.0
    _last_tick_time = time.monotonic()

    if start_x is not None:
        _cur_x = float(start_x)

    elif MOVEMENT_PATTERN == MovementPattern.RECTANGLE:
        _cur_x = float(SNAKE_PAN_MIN)

    elif MOVEMENT_PATTERN == MovementPattern.ELLIPSE:
        _cur_x = float(SNAKE_PAN_MAX)

    elif MOVEMENT_PATTERN == MovementPattern.CIRCLE:
        radius = min(
            _pan_radius,
            _tilt_radius
        )

        _cur_x = float(
            _pan_path_center + radius
        )

    else:
        _cur_x = float(
            _pan_path_center
        )

    if start_y is not None:
        _cur_y = float(start_y)

    elif MOVEMENT_PATTERN == MovementPattern.RECTANGLE:
        _cur_y = float(
            SNAKE_CENTER_TILT
        )

    else:
        _cur_y = float(
            _tilt_path_center
        )

    _cur_x = _clamp(
        _cur_x,
        PAN_MIN,
        PAN_MAX
    )

    _cur_y = _clamp(
        _cur_y,
        TILT_MIN,
        TILT_MAX
    )

    return _write_servos(
        _cur_x,
        _cur_y
    )


def snake_tick():
    """
    Non-blocking движење.

    Во главниот loop само повикувај:

        snake_tick()

    Формата автоматски ја зема од:

        MOVEMENT_PATTERN
    """

    global _cur_x
    global _cur_y

    global _rectangle_index
    global _path_phase
    global _last_tick_time

    now = time.monotonic()

    dt = now - _last_tick_time
    _last_tick_time = now

    # Ако главниот код бил блокиран подолго,
    # спречува ненадеен голем скок.
    dt = _clamp(
        dt,
        0.0,
        0.08
    )

    # --------------------------------------------------------
    # RECTANGLE / SNAKE
    # --------------------------------------------------------

    if MOVEMENT_PATTERN == MovementPattern.RECTANGLE:
        if not _RECTANGLE_POINTS:
            return _write_servos(
                _cur_x,
                _cur_y
            )

        target_x, target_y = (
            _RECTANGLE_POINTS[
                _rectangle_index
            ]
        )

        dx = float(target_x) - _cur_x
        dy = float(target_y) - _cur_y

        distance = math.sqrt(
            dx * dx + dy * dy
        )

        step = float(SNAKE_SPEED) * dt

        if distance <= max(
            step,
            SNAKE_EPS
        ):
            _cur_x = float(target_x)
            _cur_y = float(target_y)

            _rectangle_index = (
                _rectangle_index + 1
            ) % len(_RECTANGLE_POINTS)

        elif distance > 0:
            ratio = step / distance

            _cur_x += dx * ratio
            _cur_y += dy * ratio

    # --------------------------------------------------------
    # ELLIPSE / CIRCLE / INFINITY
    # --------------------------------------------------------

    else:
        cycle_seconds = max(
            1.0,
            float(
                MOVEMENT_CYCLE_SECONDS
            )
        )

        _path_phase += (
            dt / cycle_seconds
        )

        _path_phase %= 1.0

        _cur_x, _cur_y = (
            _movement_position(
                MOVEMENT_PATTERN,
                _path_phase
            )
        )

    return _write_servos(
        _cur_x,
        _cur_y
    )


def snake_loop(delay=0.02):
    """
    Самостоен тест на движењето.

    Ctrl+C за прекин.
    """

    snake_reset()

    print(
        "Movement pattern:",
        MOVEMENT_PATTERN.value
    )

    try:
        while True:
            snake_tick()
            time.sleep(delay)

    except KeyboardInterrupt:
        print("\nStop.")
        zatvori_serva()


def _stabiliziraj_motion_frame(gray1, gray2):
    """
    Се обидува да го компензира глобалното движење од pan/tilt.

    Ако камерата малку се поместила, вториот frame се враќа назад
    за да се споредува истата сцена.
    """

    height, width = gray1.shape[:2]

    # Работи на помала слика за да не го товари многу Raspberry Pi.
    detection_width = min(width, 320)
    scale = detection_width / float(width)

    small_width = max(64, int(width * scale))
    small_height = max(48, int(height * scale))

    small1 = cv2.resize(
        gray1,
        (small_width, small_height),
        interpolation=cv2.INTER_AREA
    )

    small2 = cv2.resize(
        gray2,
        (small_width, small_height),
        interpolation=cv2.INTER_AREA
    )

    small1 = cv2.GaussianBlur(small1, (7, 7), 0)
    small2 = cv2.GaussianBlur(small2, (7, 7), 0)

    try:
        shift, response = cv2.phaseCorrelate(
            np.float32(small1),
            np.float32(small2)
        )

        shift_x = shift[0] / scale
        shift_y = shift[1] / scale

    except Exception as error:
        if verbose:
            print("[MOTION] stabilization error:", error)

        return gray2, 0.0, 0.0, False

    maximum_x = width * MOTION_MAX_CAMERA_SHIFT_RATIO
    maximum_y = height * MOTION_MAX_CAMERA_SHIFT_RATIO

    camera_moved_too_much = (
        abs(shift_x) > maximum_x or
        abs(shift_y) > maximum_y
    )

    if camera_moved_too_much:
        return gray2, shift_x, shift_y, True

    # phaseCorrelate кажува колку се поместил frame2.
    # За да го порамниме, го враќаме во обратна насока.
    transform = np.float32([
        [1, 0, -shift_x],
        [0, 1, -shift_y]
    ])

    aligned = cv2.warpAffine(
        gray2,
        transform,
        (width, height),
        flags=cv2.INTER_LINEAR,
        borderMode=cv2.BORDER_REPLICATE
    )

    return aligned, shift_x, shift_y, False
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

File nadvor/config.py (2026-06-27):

# -*- coding: utf-8 -*-
# config.py - SITE postavki za pametna vrata (BEZ tajni - tie odat vo .env!)
#
# HARDVERSKA SHEMA (spored tvoeto povrzuvanje):
#   Fingerprint UART : GPIO14 (TXD) , GPIO15 (RXD)        -> /dev/serial0
#   PCA9685   I2C-1  : GPIO2 (SDA1) , GPIO3 (SCL1)        -> /dev/i2c-1 (default)
#   LCD       I2C-3  : GPIO12 (SDA) , GPIO16 (SCL)        -> /dev/i2c-3 (softverski)
#   RC522     SPI    : GPIO10 MOSI, GPIO9 MISO, GPIO11 SCLK, GPIO8 CE0, GPIO25 RST
#   Tastatura 4x4    : redovi 19,13,6,5  koloni 21,20,22,27
#   Pan/Tilt serva   : PCA9685 kanal 0 (pan) , kanal 3 (tilt)
#   Brava/rele       : GPIO26 (ne be spomnata - smeni ako treba)

# ---------------- Prikaz / Debug ----------------
debug = True
verbose = True
show_fps = True
window_on = True      # True = OpenCV prozorec (treba GUI desktop); False za SSH
CIRCLE_SIZE = 8
LINE_THICKNESS = 2
WINDOW_BIGGER = 1

# ---------------- GPIO pinovi ----------------
GPIOZERO_DOOR_PIN = 26          # rele za bravata

# Tastatura 4x4 (BCM broevi)
# Konektor od LEVO kon DESNO: pin1..pin8
#   pin1=19 pin2=13 pin3=6 pin4=5  | pin5=21 pin6=20 pin7=22 pin8=27
# Standardno: prvite 4 = REDOVI, vtorite 4 = KOLONI.
# Ako tipkите izleguvaat pogreshno -> zameni gi dvete grupi (vidi README).
KEYPAD_ROW_PINS = [19, 13, 6, 5]
KEYPAD_COL_PINS = [21, 20, 22, 27]

# ---------------- FUSION HAT serva (pan/tilt) ----------------
# Kanali se STRINGOVI "P0".."P11" spored oznakите na Fusion HAT plочката!
# Smeni gi spored kade fizicki gi vklucki servata.
PCA_PAN_CHANNEL = "P0"      # pan servo (levo-desno)
PCA_TILT_CHANNEL = "P1"     # tilt servo (gore-dolu)

# ---------------- Pan/Tilt agli (CHISTI servo stepeni 0-180) ----------------
# x = pan (levo-desno), y = tilt (gore-dolu). 90 = sredina.
PAN_DIR = 1              # 1 ili -1 ako pan se dvizi NAOPAKU
TILT_DIR = 1             # 1 ili -1 ako tilt se dvizi NAOPAKU

PAN_MIN = 30             # najlev agol pri skeniranje
PAN_MAX = 150            # najdesen agol
TILT_MIN = 70            # najdolen/najgoren agol na tilt
TILT_MAX = 110           # drug kraj na tilt
PAN_START = 90           # pochetna pan pozicija (gleda pravo napred)
TILT_START = 90          # pochetna tilt pozicija (visina na lice)

SCAN_STEP = 2            # stepeni po cekor pri skeniranje (MAL = mazno)
TILT_STEP = 10           # kolku tilt da skokne koga pan ke stigne kraj (nov red)
SCAN_DELAY = 0.03        # pauza po sekoj cekor (mazno tempo)

TRACK_DIV = 25           # sledenje: POGOLEM = pomazno/pobavno
TRACK_MAX_STEP = 6       # max stepeni po cekor pri sledenje na glava
STILL_TIMEOUT = 3.0      # sek po posledno dvizhenje da probuva lice pred scan

# ---------------- LCD (I2C-3, softverski bus) ----------------
LCD_ENABLED = True
LCD_I2C_PORT = 1            # HARDVERSKA i2c-1 (GPIO2/3), PCA go nema veke
LCD_I2C_ADDRESS = 0x27     # proveri so: i2cdetect -y 3  (chesto 0x27 ili 0x3f)
LCD_COLS = 16
LCD_ROWS = 2

# ---------------- Kamera ----------------
WEBCAM = False
WEBCAM_SRC = 0
WEBCAM_WIDTH = 640
WEBCAM_HEIGHT = 480
WEBCAM_HFLIP = True
WEBCAM_VFLIP = False

CAMERA_WIDTH = 320
CAMERA_HEIGHT = 240
CAMERA_HFLIP = False
CAMERA_VFLIP = True
CAMERA_ROTATION = 0
CAMERA_FRAMERATE = 15
FRAME_COUNTER = 1000

# ---------------- Tajmeri za sostojbi ----------------
timer_motion = 3
timer_face = 2
timer_pan = 1

# ---------------- Smiruvanje na sledenjeto ----------------
HEAD_FACTOR = 0.18         # "glava" = 18% od vrvot na motion box

# Skeniranje koga nema nishto (MALI cekori = mazno, kako originalot)


# ---------------- Face recognition ----------------
ENCODINGS_FILE = "encodings.pickle"
CASCADE_FILE = "haarcascade_frontalface_default.xml"
MIN_PERCENT_MATCH = 50

PRIORITET_IMINJA = ["Vase", "Valentina", "Done", "unknown"]

EMAILS = {
    "Done": "done.gogov.1987.dg@gmail.com",
    "Valentina": "valegogovadv@gmail.com",
    "Vasil": "vasil.gogov119@gmail.com",
}
DEFAULT_EMAIL = "done.gogov.1987.dg@gmail.com"

# ---------------- RFID ----------------
RFID_DB_FAJL = "korisnici.json"

# ---------------- Vrata ----------------
DOOR_OPEN_SECONDS = 60

# ---------------- Alert za nepoznato lice ----------------
# Kolku sekundi da chekame pred da pratime NOV alert za nepoznat
# (za da ne spamame email ako nepoznatiot stoi pred kamerata)
UNKNOWN_ALERT_COOLDOWN = 120

# ---------------- OpenCV motion ----------------
MIN_AREA = 800        # bea 2000; so shirokata slika chovekot e pomal
THRESHOLD_SENSITIVITY = 25
BLUR_SIZE = 10

# ---------------- Tastatura znaci ----------------
PASSWORD_START_CHARACTER = "*"
PASSWORD_END_CHARACTER = "#"

# ---------------- Boi (BGR) ----------------
blue = (255, 0, 0)
green = (0, 255, 0)
red = (0, 0, 255)

# ---------------- Presmetani vrednosti ----------------
cam_cx = CAMERA_WIDTH / 2
cam_cy = CAMERA_HEIGHT / 2
big_w = int(CAMERA_WIDTH * WINDOW_BIGGER)
big_h = int(CAMERA_HEIGHT * WINDOW_BIGGER)

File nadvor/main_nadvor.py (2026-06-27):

#!/usr/bin/env python3
# -*- coding: utf-8 -*-
# main_nadvor.py - RPi4 NADVOR - sledi LOKALNO, prakja surovi podatoci VNATRE.
# ============================================================================
# NADVOR ne odluchuva NISHTO. Samo:
#   - sledi dvizhenje/lice lokalno (mazni serva)
#   - koga ima lice -> slika -> prati VNATRE -> dobiva "Done"/"unknown"
#   - ako poznato -> vodi niz faktori (otpechatok -> OTP -> RFID),
#     sekoj pat prakja SUROVO citanje VNATRE, VNATRE proveruva
#   - VNATRE odluchuva i otkluchuva
#
# Koristi gi POSTOECHKITE moduli: config, kamera, sledenje, tastatura,
# otpechatok, lcd (isti kako dosega). Plus: vrska, rfid_chitac, config_vrska.

import base64
import socket
import ssl
import time

# TLS sertifikati (kopiraj gi tuka - vidi generiraj_sertifikati.sh)
CA_CRT = "ca.crt"
CLIENT_CRT = "nadvor.crt"
CLIENT_KEY = "nadvor.key"

import cv2

from config import (cam_cx, cam_cy, window_on, CIRCLE_SIZE, LINE_THICKNESS,
                    green, PAN_START, TILT_START, SCAN_STEP, PAN_MIN, PAN_MAX,
                    TILT_MIN, TILT_MAX, TILT_STEP, SCAN_DELAY,
                    TRACK_DIV, TRACK_MAX_STEP, STILL_TIMEOUT)
from config_vrska import VNATRE_IP, VNATRE_PORT, TIMEOUT
from vrska import poslji, primi, klient_kontekst
import sledenje
import tastatura
import lcd
from kamera import WebcamVideoStream
from otpechatok import get_fingerprint, finger
import rfid_chitac


def povrzi_vnatre():
    """Otvori SIFRIRANA (TLS) vrska kon RPi5 vnatre."""
    ctx = klient_kontekst(CA_CRT, CLIENT_CRT, CLIENT_KEY)
    raw = socket.socket(socket.AF_INET, socket.SOCK_STREAM)
    raw.settimeout(TIMEOUT)
    raw.connect((VNATRE_IP, VNATRE_PORT))
    # server_hostname mora da se sovpagja so CN vo sertifikatot ("vnatre")
    return ctx.wrap_socket(raw, server_hostname="vnatre")


def slika_vo_b64(bgr):
    ok, buf = cv2.imencode(".jpg", bgr, [cv2.IMWRITE_JPEG_QUALITY, 80])
    return base64.b64encode(buf).decode("ascii")


def proces_otkluchuvanje(img_frame):
    """
    Vodi go korisnikot niz faktorite, prakajki surovo VNATRE.
    Vrakja True ako VNATRE otkluchi.
    """
    try:
        s = povrzi_vnatre()
    except Exception as e:
        print("[NADVOR] ne moze da se povrze so VNATRE:", e)
        lcd.poraka("Nema vrska", "so vnatre")
        return False

    try:
        # ---- 1. LICE ----
        lcd.poraka("Proveruvam", "lice...")
        poslji(s, {"tip": "PROVERI_LICE", "slika": slika_vo_b64(img_frame)})
        odg = primi(s)
        rez = (odg or {}).get("rezultat")
        if rez in (None, "nema_lice"):
            lcd.poraka("Nema lice", "")
            return False
        if rez == "unknown":
            lcd.poraka("Nepoznato lice", "Odbieno")
            time.sleep(2)
            return False
        osoba = rez
        lcd.poraka(f"Zdravo {osoba}", "Stavi prst")

        # ---- 2. OTPECHATOK ----
        if not get_fingerprint():
            lcd.poraka("Otpechatok", "Odbien")
            time.sleep(2)
            return False
        poslji(s, {"tip": "OTPECHATOK", "id": finger.finger_id})
        if not (primi(s) or {}).get("ok"):
            lcd.poraka("Otpechatok", "ne se sovpagja")
            time.sleep(2)
            return False

        # ---- 3. OTP (VNATRE prati email; korisnik vnesuva na tastatura) ----
        lcd.poraka("OTP na email", "Vnesi: * kod #")
        vnes = ""
        is_start = False
        while True:
            k = tastatura.scankey()
            if k is None:
                continue
            if k == "*":
                is_start = True
                vnes = ""
            elif k == "#":
                break
            elif is_start:
                vnes += k
        poslji(s, {"tip": "OTP", "vnes": vnes})
        if not (primi(s) or {}).get("ok"):
            lcd.poraka("Pogreshen OTP", "Odbieno")
            time.sleep(2)
            return False

        # ---- 4. RFID ----
        lcd.poraka("Prinesi", "karta")
        uid, token = rfid_chitac.procitaj_karta()
        if uid is None:
            lcd.poraka("Greshka karta", "")
            return False
        poslji(s, {"tip": "RFID", "uid": uid, "token": token})
        finalno = primi(s) or {}
        if finalno.get("tip") == "OTKLUCENO":
            lcd.poraka("Dobredojde", finalno.get("osoba", ""))
            return True
        lcd.poraka("Karta odbiena", "")
        time.sleep(2)
        return False
    finally:
        s.close()


def main():
    lcd.poraka("Pametna vrata", "Startuvam...")
    vs = PiVideoStream().start()
    time.sleep(2.0)

    x, y = PAN_START, TILT_START
    dx = SCAN_STEP
    x, y = sledenje.postavi(x, y)
    sledi = False
    posledno = 0.0
    lcd.poraka("Skeniram...", "")

    while True:
        f1 = vs.read()
        if f1 is None:
            continue
        g1 = cv2.cvtColor(f1, cv2.COLOR_BGR2GRAY)
        time.sleep(0.03)
        f2 = vs.read()
        g2 = cv2.cvtColor(f2, cv2.COLOR_BGR2GRAY)
        centar = sledenje.motion_centar(g1, g2)

        if centar is not None:
            # MOTION -> sledi LOKALNO (mazno)
            sledi = True
            posledno = time.time()
            cx, cy = centar
            x += max(-TRACK_MAX_STEP, min(TRACK_MAX_STEP, int((cx - cam_cx) / TRACK_DIV)))
            y += max(-TRACK_MAX_STEP, min(TRACK_MAX_STEP, int((cy - cam_cy) / TRACK_DIV)))
            x, y = sledenje.postavi(x, y)
        else:
            if sledi and (time.time() - posledno < STILL_TIMEOUT):
                # nekoj zastana -> probaj otkluchuvanje (slika ide VNATRE)
                if proces_otkluchuvanje(f2):
                    print("[NADVOR] VNATRE otkluci!")
                sledi = False
                lcd.poraka("Skeniram...", "")
            else:
                # skeniraj (snake)
                sledi = False
                x += dx
                if x >= PAN_MAX:
                    x = PAN_MAX; dx = -SCAN_STEP; y += TILT_STEP
                    if y >= TILT_MAX:
                        y = TILT_MIN
                elif x <= PAN_MIN:
                    x = PAN_MIN; dx = SCAN_STEP; y += TILT_STEP
                    if y >= TILT_MAX:
                        y = TILT_MIN
                x, y = sledenje.postavi(x, y)
                time.sleep(SCAN_DELAY)

        if window_on and centar is not None:
            cv2.circle(f2, centar, CIRCLE_SIZE, green, LINE_THICKNESS)
            cv2.imshow("Nadvor - q izlez", f2)
        if window_on and cv2.waitKey(1) & 0xFF == ord('q'):
            break

    vs.stop()


if __name__ == "__main__":
    try:
        main()
    except KeyboardInterrupt:
        print("\nKraj.")
    finally:
        sledenje.zatvori_serva()
